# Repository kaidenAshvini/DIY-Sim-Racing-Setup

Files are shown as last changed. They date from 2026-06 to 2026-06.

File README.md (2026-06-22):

# DIY Sim Racing Setup
It's no secret that simulation racing setups are ridiculously expensive (with high end setups reaching thousands of dollars!). I sought to create a DIY Sim Racing Setup, using many materials I and other hobbyists would already have access to, equipped with a force-feedback wheel and 3-pedal setup. In addition, I aimed for the wheel base to be very compact while offering a driving experience comparable to mid-range setups, for a far cheaper cost.

## Specs
The [Wheelbase](CAD/Wheel%20Assembly.step) features a 220W 48V Brushless DC Motor for punchy, high-torque force feedback. It reads position through a 600 P/R Incremental Rotary Encoder, which is responsive and accurate. It is also marginally adjustable, with 3 height settings and 10 degrees of adjustability.

The [Pedals](CAD/Wheel%20Assembly.step) feature torsion springs, adjustable end-stops, and rotary encoders.

## Zine

_Side note:_ I will update this Zine with an IRL picture as soon as I build it

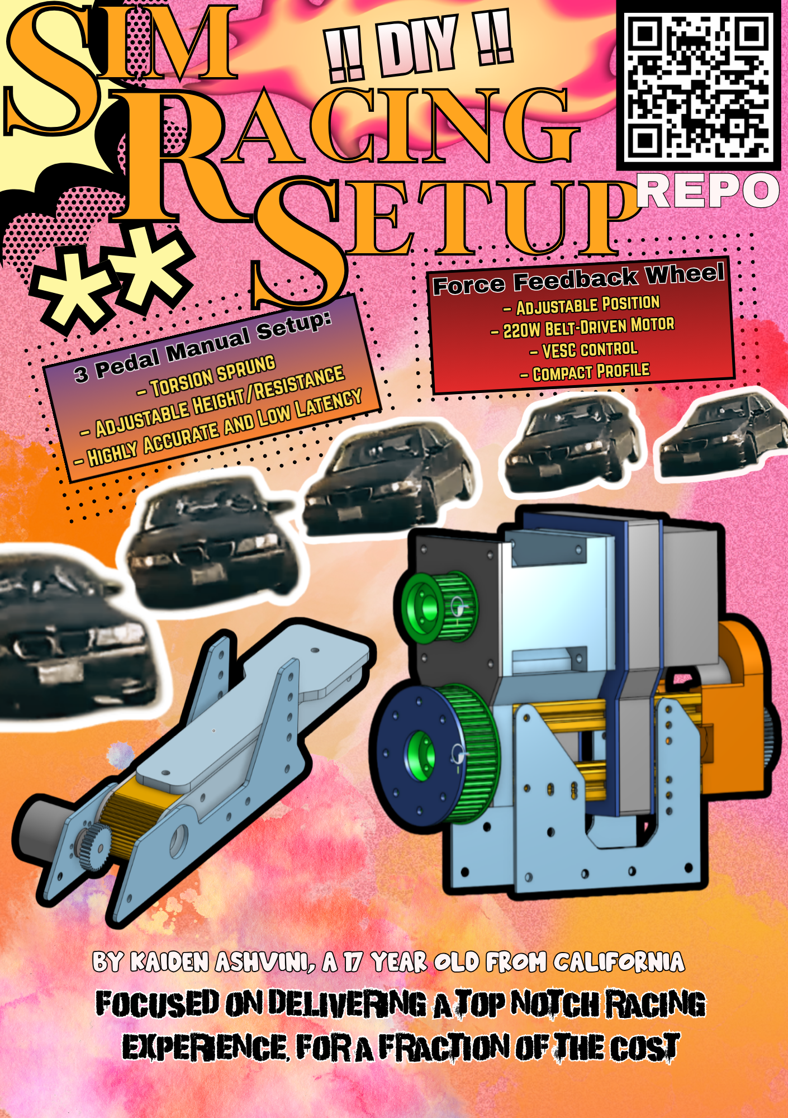
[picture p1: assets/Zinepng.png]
The car is from real pictures of my project car!


## Demo
https://www.youtube.com/watch?v=LTqkKbJHrKM

## Design Philosophy:
While I do have many years of experience on an FTC robotics team (Roboavatars #7303), I am fully a software member. This project was my first attempt at CADing and building a physical project from scratch! Keep this in mind as you read through these designs, and please let me know at kaidenashvini@gmail.com of any mistakes I may have made!

Remember, while I have flushed out a completed project that works for me, feel free to adapt to whatever materials you have on hand. This will keep costs very low, as it did in my case, and will make your personal project far more convenient to complete!

1. ### [Wheelbase](CAD/Wheel%20Assembly.step)
    - **Using 20x20 Extrusions**
        - I have access to plenty of these 20x20 McMaster-Carr extrusions through my robotics team. They are cheap, rigid, and very convenient.
    - **Front Mount**
        - My CAD features a strange design for mounting the force-feedback motor, as it recesses the motor by a few inches. This provides clearance for the inclusion of a shaft coupler (neccesary to extend the motor shaft to mount a 25mm pulley), and it also provides a sturdier rear mounting position.
    - **Motor Rear Mount**
        - The Motor Rear Mount serves to reinforce the motor mount, as features two 3/8ths inch aluminum plates.
    - **Encoder Rear Mount**
        - I geared the encoder to directly to the drive shaft, and found a convenient place to mount it. The mount also keeps the extrusions in place.
        - Gearing an encoder, in my opinion, is preferential to belting it. Gearing will have less lag/backlash, and are also easier to 3d print
    - **3D Printed Pulleys**
        - Metal pulleys are better in *nearly* every way, **but there are a few reasons I chose to 3D print them**. I chose 3D printed pulleys to keep costs down, and because it makes mounting the wheel way easier. I made mine out of annealed carbon nylon (which many have reported online to be very sturdy!), and the design features embedded nuts and space to attach a flange coupler for compactness.
    - **Flipsky Vesc Control**
        - This motor controller is common, and it is listed as compatible with the firmware I've decided to go with for this project. They are relatively common, and I had one on hand. In reality, any controller works as long as it's compatible with the firmware listed in [Software](firmware/README.md).

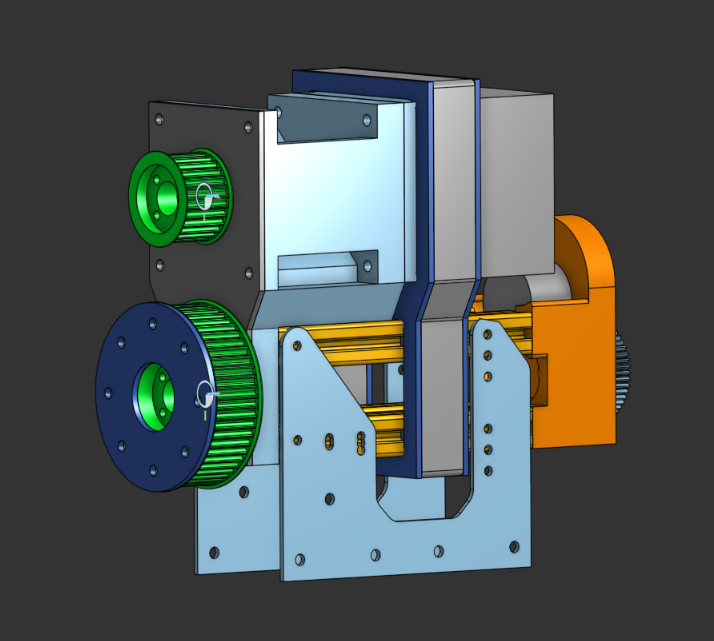
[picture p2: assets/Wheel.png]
Wheel Base, 0 deg Tilt


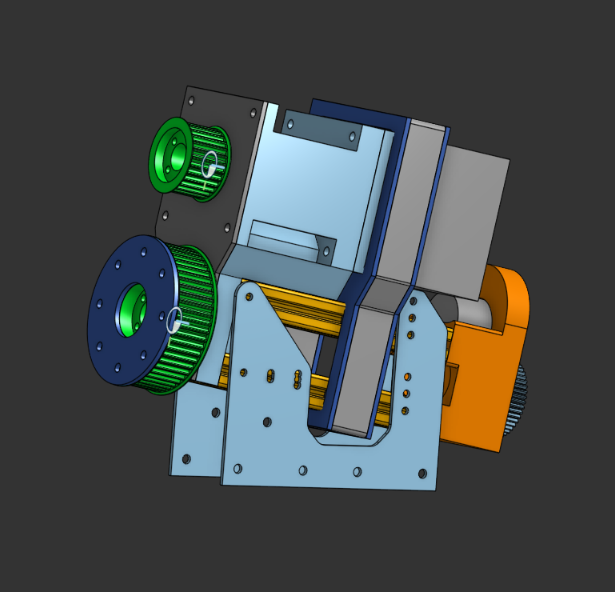
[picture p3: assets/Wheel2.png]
Wheel Base, 10 deg Tilt


2. ### [Pedals](CAD/Pedal%20Assembly.step)
    - **Using Torsion Spring**s
        - I have torsion springs beneath the pedal shafts, which aim offer a realistic feel similar to real pedals.
    - **Pedal Design/Sizing**
        - I based the pedal sizes off of real pedals from IRL car pedals. This (hopefully) makes it easy to heel-toe.
    - **Reading Pedal Position**
        - I chose to use a geared 3D print for low-latency and high-accuracy (by using gear ratios to my advantage)

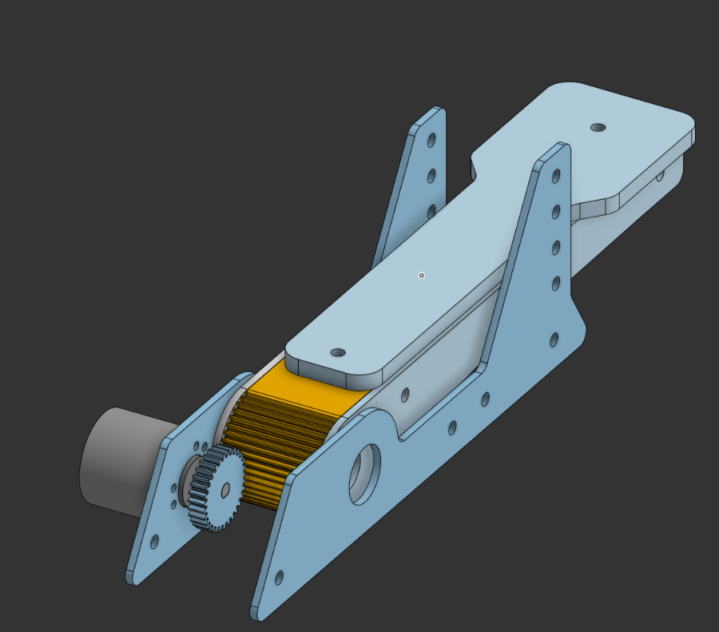
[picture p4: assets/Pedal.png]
Pedals, Front/Top Down View

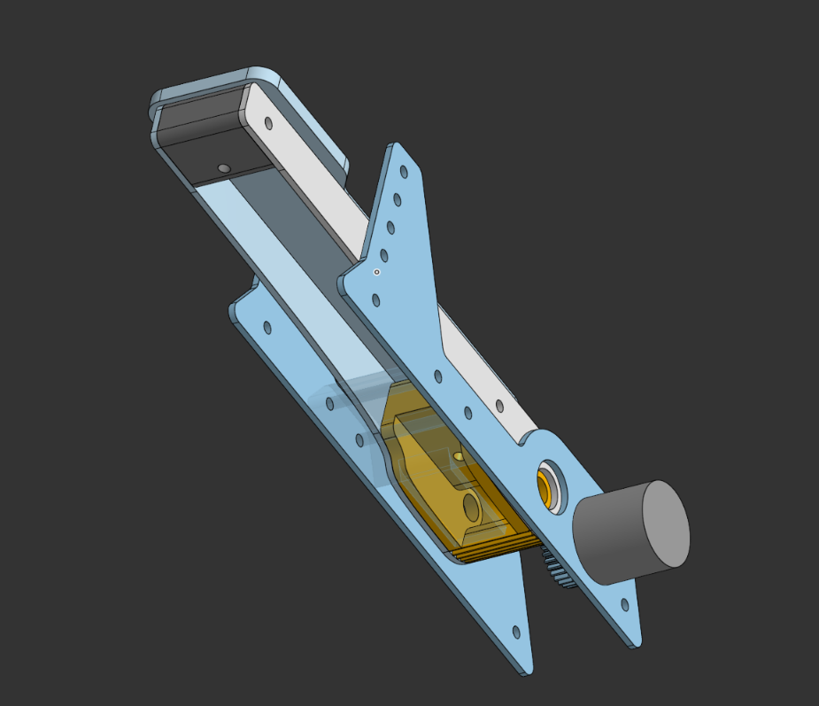
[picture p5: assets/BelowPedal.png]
Pedals, Bottom Torsion Spring Mount View


## Adaptation:
This is a fully-flushed out project that I've put together. I used the resources that I have available to create the best product I could within a reasonable cost. However, I understand that not everyone will have access to the exact same tools and materials as I did. In this case, **IMPROVISE**.

When this project is shipped, an [Adaptation Guide](CAD/README.md) will be added.

## Building Tips:
1. ### Wheel Base
    1. Tapping your Extrusions
        - Use a M5 tap, and preferably a drill press, to tap the ends of your extrusions. For the 1/2 ft extrusions, do it for both sides. Otherwise, tap as neccesary
        - Use a cutting fluid or lubricant, I used WD-40
        - **Take your time**, make sure these come out straight
    2. Printing
        - You will want to print each of these parts to the most sturdy setting you can, with the strongest material you have available, especially if you aren't using the reinforcement plates.
    3. Assembly
        - Mount the Rotary Encoder to the [Encoder Rear Mount](CAD/Wheel/Steering%20Column%20Rear%20Mount.step) (this may be a bit tricky, just keep trying)
        - Mount the [Encoder Rear Mount](CAD/Wheel/Steering%20Column%20Rear%20Mount.step) to 4 tapped extrusions
        - Slide the [Rear Motor Mount](CAD/Wheel/Rear%20Motor%20Mount.step) into the 4 tapped extrusions. Slide the BLDC motor in, as well
        - Mount the [Front Motor Mount](CAD/Wheel/Steering%20Column%20Front%20Mount.step) to the other side of the 4 tapped extrusions. Screw in the 4 motor mounting screws.
        - Attach Flange Bearings (Flange facing outward) to the [Front Motor Mount](CAD/Wheel/Steering%20Column%20Front%20Mount.step) and [Endstop](CAD/Wheel/Steering%20Column%20Rear%20Mount.step)
        - Slide the 12mm dia. x 400mm length D-shaft into the bearings. Mark enough clearance for the Hub Adapter and Shaft Gear (including the flange coupling)
        - Cut the shaft to size. Drop the 14mm x 12mm Shaft Coupler into the top of the Front Motor Mount, and take the smaller peice of the D-shaft to attach to the end of the Shaft Coupler
        - Assemble the gears and pulleys ([Hub Adapter](CAD/Wheel/Hub%20Adapter.step), [Motor Pulley](CAD/Wheel/Motor%20Pulley.step), [Shaft Gear](CAD/Wheel/Shaft%20Gear.step), [Encoder Gear](CAD/Pedal/Encoder%20Gears.step)) using M4 nuts/bolts and the Flange Coupler
        - Test fit and mark the position of the Flange Couplings on the shafts. Disassemble the Pulleys/Gears
        - Attach the Flange Couplings with the shaft mounted and tighten
        - Attach the Gears/Pulleys to their respective Flange Couplings
        - Attach the Belt. This may be easier if you detach the motor output shaft and steering column shaft and slide both in at the same time with the pulley in place
        - Attach the [Encoder Gear](CAD/Pedal/Encoder%20Gears.step) to the encoder
    4. Wiring
        - Use a spare power cord. Strip and attach ferrules to the end. Apply to Power Supply Unit
        - Motor wires to VESC (color corresponding wires)
        - PSU wires to VESC (color corresponding RED/BLACK 10-12 gauge wires)
        - COMM TX/RX/GND wires to STM32 (check wiring diagram for the color correspondance). Ensure that TX/RX are crossed!!
        - Attach 4.7k ohm pull-up resistors to a small jumper wire to both the A and B (Green/White) wires. I used Dupont wires for easy connection.
        - Attach GND,A,B,5v to encoder. Attach the small jumper wire from the previous step to a 3.3V output
        - Splice a USB cable (data transfer, must have 4 wires) with Dupont wires. Refer to your STM32's pinout for the placement of USBs

2. ### Pedals
    1. Side Walls
        - I CNCed my side walls with either aluminum or polycarbonate. You can even print them, although I cannot guarantee their longevity.
    2. Assembly
        - Shave any excess burr or debris off the 3D prints and CNC cuts
        - Mount the Rotary Encoder to a [Pedal Wall](CAD/Pedal/Pedal%20Base.step)
        - Mount 2 Hex Standoffs to a pair of [Pedal Walls](CAD/Pedal/Pedal%20Base.step), one at the hole next to the Rotary Encoder and one on the desired end position
        - Mount the rest of the parts in the [Pedal](CAD/Pedal/Pedal%20(1).step)
    3. Wiring
        - Wire the encoder to 5V, GND, 2 GPIO pins on the ESP32 (internal pull-ups)

**A visual build guide is soon to come, as soon as I document the building process (after approval)**

## Software
Many high-quality DIY sim setups utilize and [OpenFFBoard](https://github.com/Ultrawipf/OpenFFBoard), which comes with all of the force-feedback control that communicates with popular sim games. However, OpenFFBoards are priced at $160, and are produced in Germany. They are fantastic products with great quality, and their software is unmatched in the DIY niche. However, for one reason or another, not everyone can get easy access to one of these boards. Instead, I rely on an ABI encoder-compatible FlipSky VESC controller, which I connect to a cheap power-supply. I also rely on an inexpensive STM32 board.

I implemented custom Force-Feedback and USB HID firmware by adapting the [VNWheel](https://github.com/hoantv/VNWheel) opensource project. This proved to be an immensely difficult task, because the TinyUsb 

This has many implications for developing software, though. The pedals will require seperate microcontrollers. I went with some old ESP32s I had lying around, and also borrowed a RP2040. I wanted to create firmware for multiple MCUs, so that you can use whatever one you want. Either way, both firmwares should be easy to adapt.

### ESP32 (w/out USB HID)
Older ESP32s do not have the correct hardware to support native USB HID, so I designed a way to read serial inputs. If you are using an RP2040 or more expensive/newer ESP32s, the USB HID interfacing should be extremely straightforward.

I will also add support for the newer ESP32s and RP2040s as soon as I get my hands on them.

### Electronics

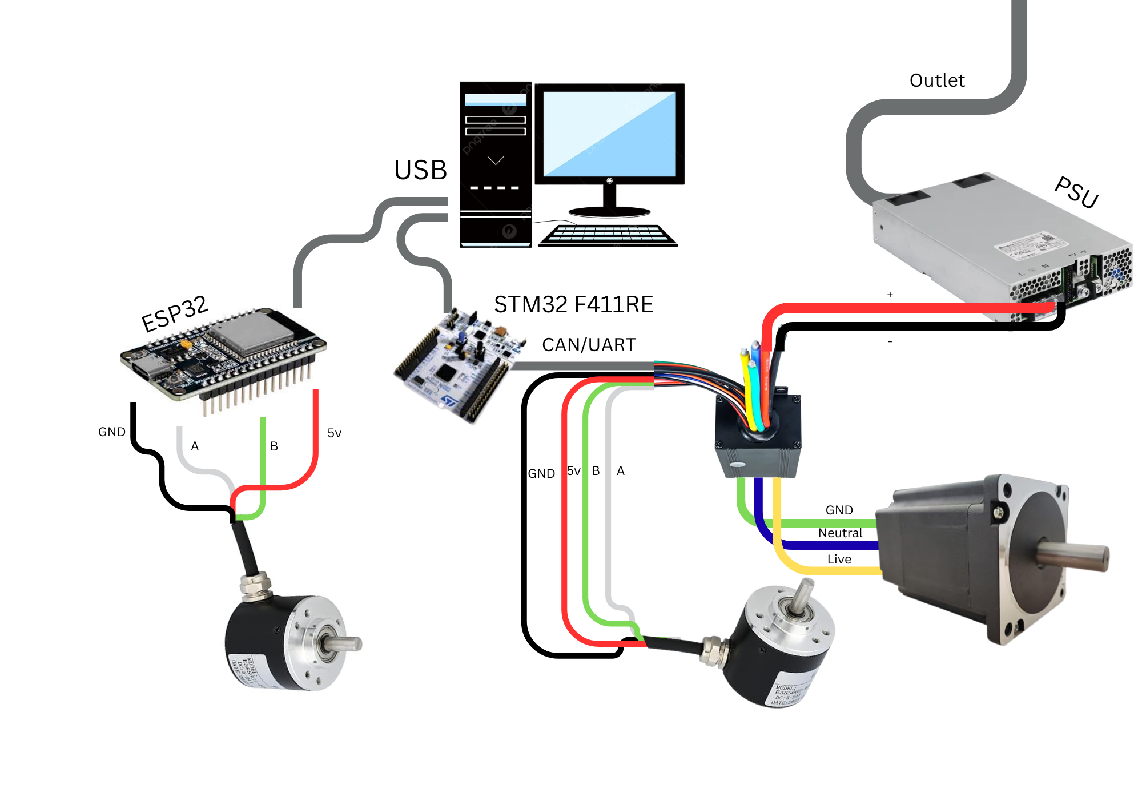
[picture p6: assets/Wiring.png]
Simplified Wiring Diagram


### BOM
About half of the cost in materials was self-sourced from previous projects, robotics teams, friends, etc. Shoutout to Theodore for challenging me to make a build for the same cost.

Learn more in [Adaptation Guide](CAD/README.md).

The BOM can be found [here](BOM/BOM.csv).

### IRL Pictures!!

I know its messy...

With/Without Wheel:
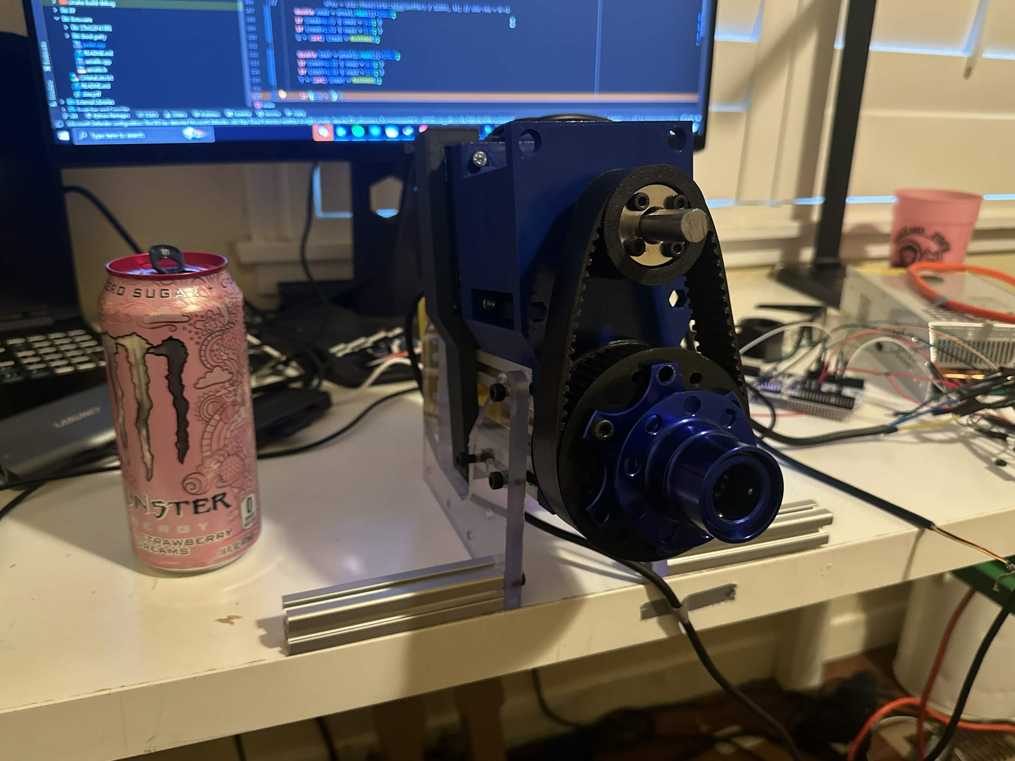
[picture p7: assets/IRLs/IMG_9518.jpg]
Without

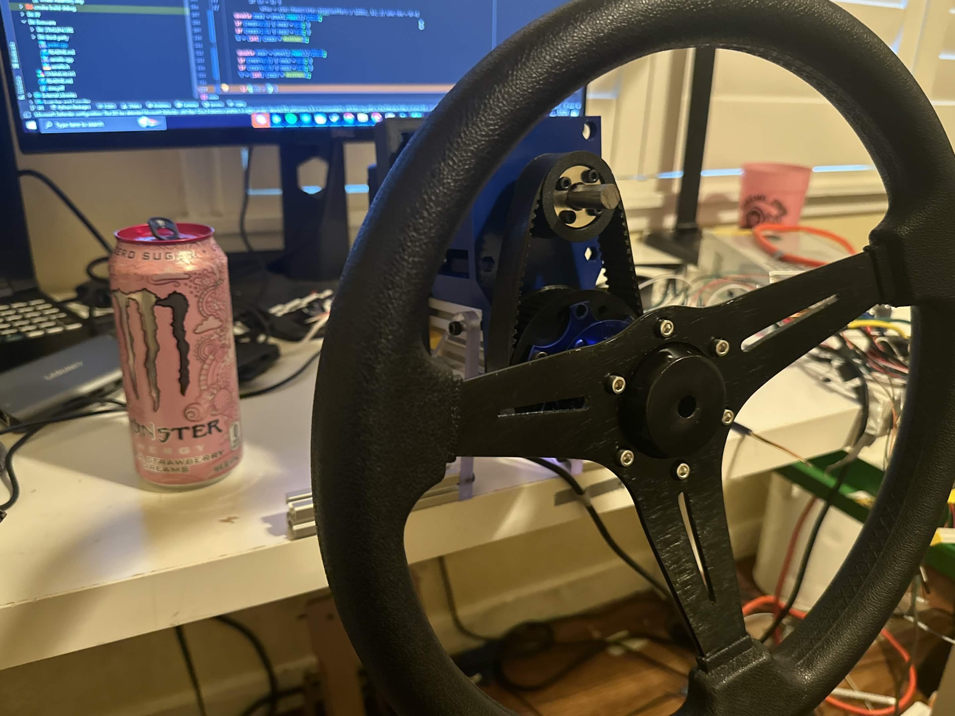
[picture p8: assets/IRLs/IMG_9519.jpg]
With


Pedal:
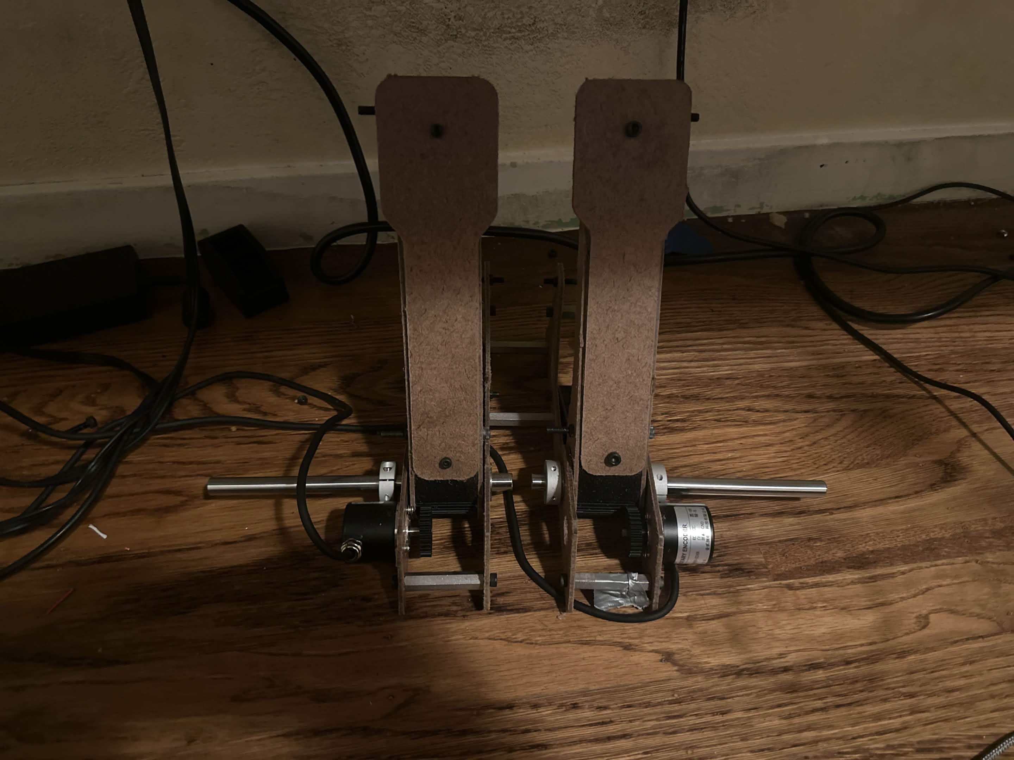
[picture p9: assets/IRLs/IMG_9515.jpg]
Pedal


Wiring:
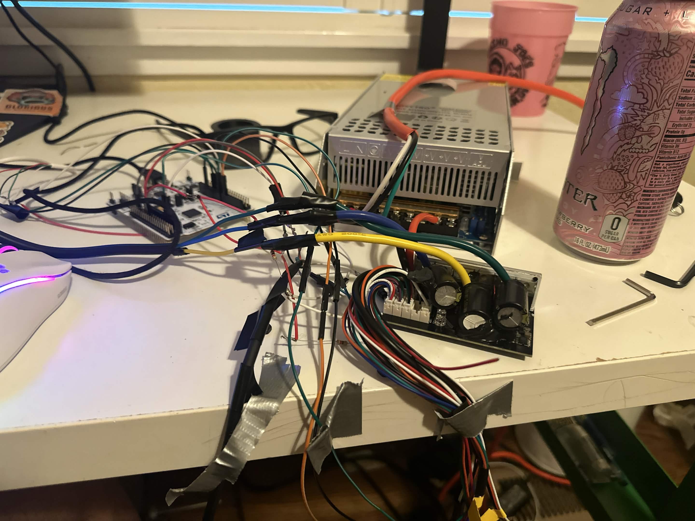
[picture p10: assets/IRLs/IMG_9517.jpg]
Wiring


Wheelbase Internals:
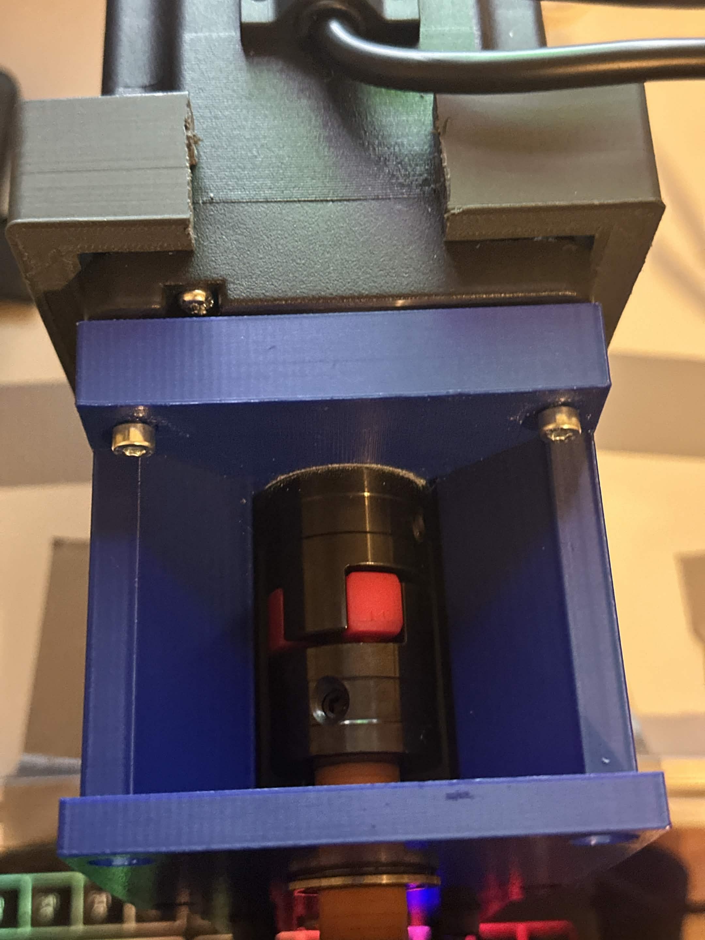
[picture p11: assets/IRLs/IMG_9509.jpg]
Shaft Coupler

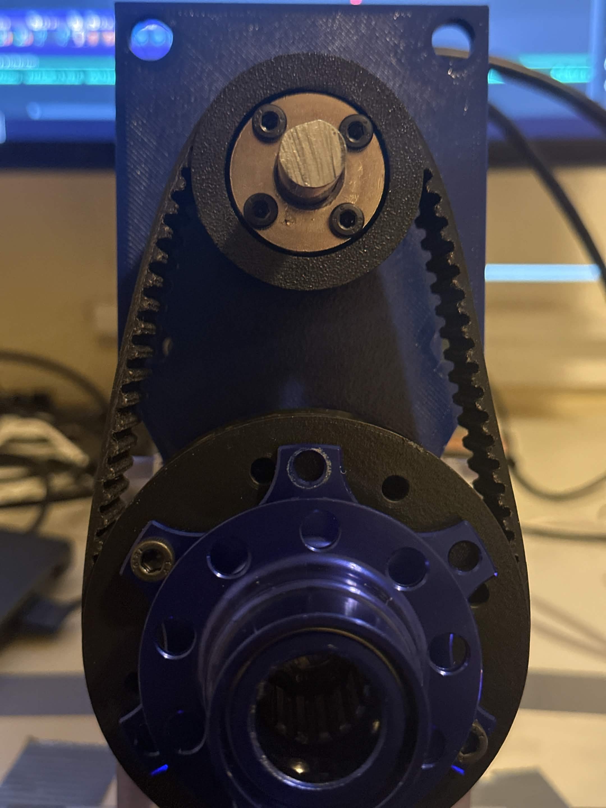
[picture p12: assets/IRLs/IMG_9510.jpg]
Pulley


### Contact

Discord: sheikaheye123

Gmail: kaidenashvini@gmail.com

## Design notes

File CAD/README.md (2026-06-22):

# Tips for Adaptation:

## Motor
Use any motor you would like (Brushless DC Motors are preferred). Adjust the mount size accordingly.

## CNC Parts
These parts can either be printed OR CNCed. Any thickness is fine.

## Pedals
Pedals can be any width. Adjust the plastic connectors accordingly or use spacers.

## Motor Controllers
You may swap the VESC for a suitable motor controller. Use the [EMC Pro](https://github.com/ebolzMagy/EMCFFBV2) software instead if you plan on doing so (it will be far easier to setup but does cost $10 dollars)

## STM32
Any board that supports USB and UART or CAN will work. If the board supports CAN (F407), use [OpenFFBoard](https://github.com/Ultrawipf/OpenFFBoard).

## Shafts
Use any shaft you'd like (preferably over 8mm). Adjust the holes in the Wheelbase and Pedals accordingly.

### Good Luck and Happy Building!!

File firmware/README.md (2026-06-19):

# Software
## Third Party Libraries

| Library | Usage | Link |
|---| - | - |
| Serialib | Allows C++ to read serial input from ESP32 | https://github.com/imabot2/serialib | 
| vJoy SDK | Allows C++ USB HID interfacing for joystick inputs | https://sourceforge.net/projects/vjoystick/files/Beta%202.x/SDK/ |
| hidapi-win | Allows low-level USB HID interfacing | https://github.com/libusb/hidapi |
| VNWheel | Open-source Force Feedback for Arduinos | https://github.com/hoantv/VNWheel |
| TinyUSB | HID interfacing with the STM32 | https://github.com/hathach/tinyusb |
| VescUart | Sending current commands over UART | https://github.com/SolidGeek/VescUart |

## Building

You will need to put the vJoyInterface.dll (specifically from third-party/vjoy/lib/amd64/) in the cmake-build-debug folder (for CLion, should be wherever your .exe file is).

I will remove this soon, because I need to flush out the firmware with the physical parts before completing it.

The STM32F411RE folder should open with Arduino IDE for flashing.

## Future Work (Coming Soon)

After completing the build, I will add support for newer ESP32s and RP2040s for pedal controls, as well. I need to source these myself to solidly test them, so I cannot configure them just yet.

I have written some low-level USB HID Descriptors for this task, included in the image below:

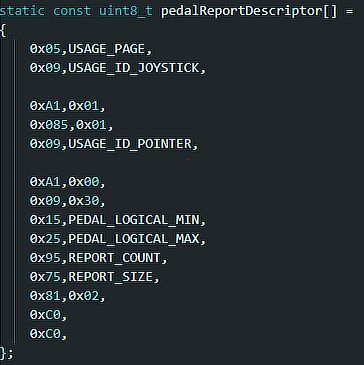
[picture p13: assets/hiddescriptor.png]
A sneak peek of what's to come!!


**Expect a full firmware/build guide once the build is started/completed!**

## Sources (Arduino IDE Sketches for ESP32 Firmware):

I used this tutorial to read ABI encoder outputs: https://www.youtube.com/watch?v=Y6BjnfwfzKE

## DIY Force-Feedback software
While originally not my intention, I ended up adapting the VNWheel library to implement custom force-feedback firmware to the STM32. This will be explained more in depth in the demo video (once it is shipped)

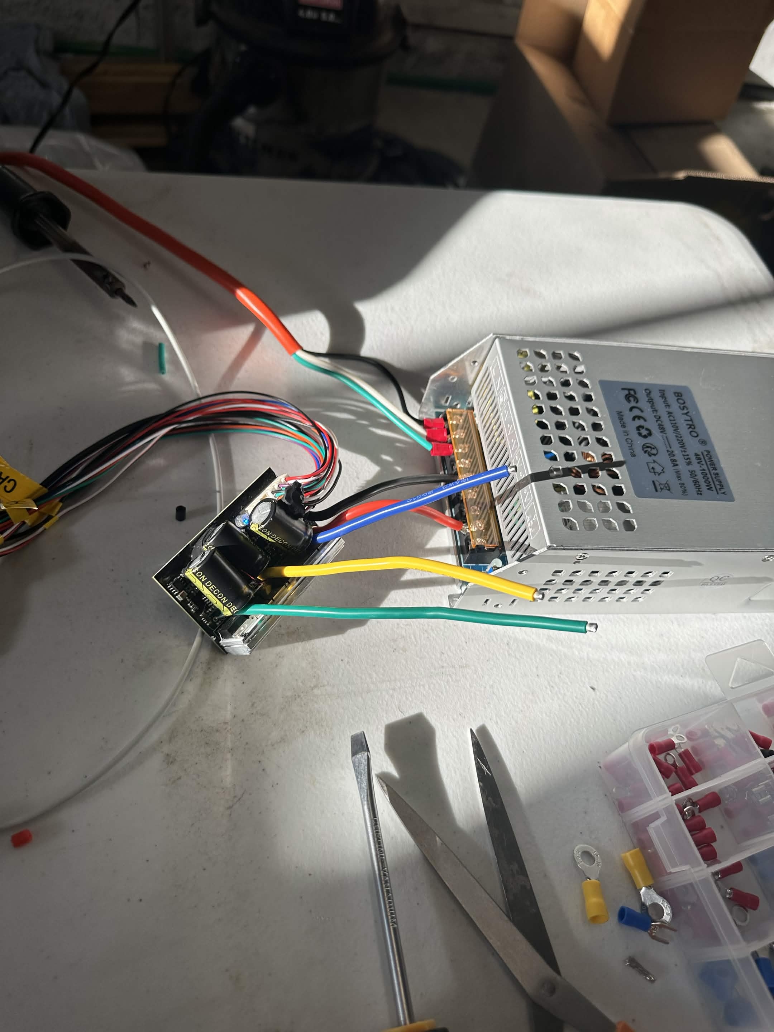
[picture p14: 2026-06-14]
assets/VESC.jpg

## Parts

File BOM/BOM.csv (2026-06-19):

PURCHASED ITEMS
Name | Description | Link | Units | Unit Price | Qty | Line Price | Running Total
Hub Adapter | 6-Hole Universal Pattern (70mm) | https://a.co/d/0caWlYnZ | Each | $27.99 | 1 | $27.99 | $27.99
Hall Effect Sensor | KY003, 3144E A3144, DC 3.3V-5V | https://a.co/d/04nWw3zB | Each | $0.86 | 10 | $8.60 | $36.59
Brushless DC Motor | 220W, 3000rpm, 48V | https://a.co/d/08rhArJE | Each | $80.50 | 1 | $80.50 | $117.09
Flange Couplings | 12mm ID x 30m OD | https://a.co/d/0i7bd3jh | Each | $1.90 | 4 | $7.60 | $124.69
Shaft Coupler | 14mm to 12mm (IDs) x 30mm OD | https://a.co/d/09o9XnUK | Each | $20 | 1 | $20 | $144.69
Amazon (Prime) Shipping | $0 |  |  |  |  | $0 | $144.69
Amazon (Prime) Local/State Tax | $14.12 |  |  |  |  | $14.12 | $158.81
D-Shaft | 12mm Diameter, 400mm Length, 6mm Flat Width | https://www.mcmaster.com/products/shafts/rotary-shafts-2~/length~100-mm/length~400-mm/rotary-shafts-2~shaft-type~d-profile/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 | Each | $18.71 | 1 | $18.71 | $177.52
Torsion Spring | 225 Deg, 0.48in Shaft Diameter | https://www.mcmaster.com/products/torsion-springs/shaft-diameter~0-48/deflection-angle~225/ | Each | $2.38 | 6 | $14.28 | $191.80
Pulley Belt | HTD5, 25mm Width, 80 Teeth, 400mm Trade Size | https://www.mcmaster.com/products/timing-belts/high-torque-htd-timing-belts-2~~/width~25-mm/number-of-teeth~80/ | Each | $44.36 | 1 | $44.36 | $236.16
McMaster-Carr Shipping |  | $14.50 |  |  |  | $14.50 | $250.66
McMaster-Carr Local/State Tax |  | $0 |  |  |  | $0 | $250.66
SELF-SOURCED ITEMS (Not compensated by Hack Club)
Name | Description | Link | Units | Unit Price | Qty | Line Price | Running Total | Source
Steering Wheel | 13.8" Diameter, 3-spoke, 6-Hole Universal Pattern (70mm) | https://a.co/d/0jdjjv3R | Each | $22.88 | 1 | $22.88 | $273.54 | Personal Supply
Rotary-Shaft | 12mm Diameter, 100mm Length | https://www.mcmaster.com/products/shafts/rotary-shafts-2~/length~100-mm/rotary-shafts-2~shaft-type~round/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 | Each | $11.62 | 2 | $23.24 | $296.78 | Robotics Team
Rotary Encoder | 600 P/R, AB 2-Phase Quadrature Output (open-collector), 5-24V | https://a.co/d/07jE8QEV | Each | $14.99 | 4 | $59.96 | $356.74 | Robotics Team
Flanged Bearing | F6901ZZ, 12mm ID x 24mm OD | https://a.co/d/0j7CwzQN | Each | $1.25 | 10 | $12.50 | $369.24 | Robotics Team
Shaft Collar | 12mm ID x 30mm OD | https://a.co/d/0fmp9A3E | Each | $2.42 | 1 | $2.42 | $371.66 | Robotics Team
Extrusion (T-Slotted Framing Rails) | 20mm x 20mm, 6" length | https://www.mcmaster.com/products/extrusions/t-slotted-framing-and-fittings~/t-slotted-framing-rails-4/rail-height~20-mm/finish~anodized/length~6/length~1-2-f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 | Each | $3.75 | 7 | $26.25 | $397.91 | Robotics Team
Standoff | M5, 10mm Hex Size, 52mm | https://www.mcmaster.com/products/standoffs/standoffs-2~/female-threaded-hex-standoffs~~/thread-size~m5/length~52-mm/performance~lightweight/ | Each | $3.91 | 4 | $15.64 | $413.55 | Robotics Team
Power Supply Unit | 48V, 20.8A, 1000W | https://a.co/d/0fD26eDp | Each | $50.99 | 1 | $50.99 | $464.54 | Personal Supply (Very overkill for this project)
STM32 | Nucleo-64, F411RE | https://a.co/d/01KzO2nj | Each | $25.42 | 1 | $25.42 | $489.96 | Personal Supply
ESP32 | NodeMCU (ESP-32S) | https://a.co/d/0g8DS4Zf | Each | $5.60 | 1 | $5.60 | $495.56 | Personal Supply
Flipsky VESC | 75100, 75V, 100A | https://a.co/d/06qzeMMU | Each | $75.99 | 1 | $75.99 | $571.55 | Personal Supply (Also overkill)
SELF-SOURCED MISC. RESOURCES (Not compensated by Hack Club)
Name | Description | Link | Units | Unit Price | Qty | Line Price | Running Total
M5 Assorted Bolts/Nuts | M5x8/10/12/16/20/25/30/35 | https://a.co/d/0ctkiRn3 | Each (kit) | $9.99 | 1 | $9.99 | $581.54
M4 Assorted Bolts/Nuts | M4x6/8/12/16/20/30 | https://a.co/d/0cXDtAtJ | Each (kit) | $9.99 | 1 | $9.99 | $591.53
Filament | PAHT-CF, PLA | https://a.co/d/0477rVy3 | Kg | $39.99 | 0.3 | $12.00 | $603.53
SELF-SOURCED TOOLS (Not compensated by Hack Club)
Drill Press
M5 0.8 Spiral Flute Tap
CNC
3D Printer
Filament Dryer

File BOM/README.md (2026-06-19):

# Sourcing

## Why Amazon?
I am well aware that Hack Club prefers sourcing electronics from less mainstream distributors than Amazon. However, for my case, I ended up saving about 20 dollars and weeks worth of waiting through using Amazon with my parent's Prime membership (free shipping and heavily reduced fees). Because I bought so few electronics, and the ones I did buy were heavy/large, shipping from Aliexpress would have costed upwards of 40 dollars, not including myriad other taxes and fees. Even if I did save some money from buying a cheaper part, the shipping would have quickly covered that cost.
## Why McMaster-Carr?
McMaster-Carr is a local company that I frequently rely on for robotics parts. They have some of the best prices for highly specified materials, and because they are very local, shipping is fast and very cheap. They offer a fixed shipping fee for as many items as you want, making bulk/bundled purchases ideal.

## Self Sourcing
I was luckily able to self-source many parts for free from friends, robotics team, and previous project.

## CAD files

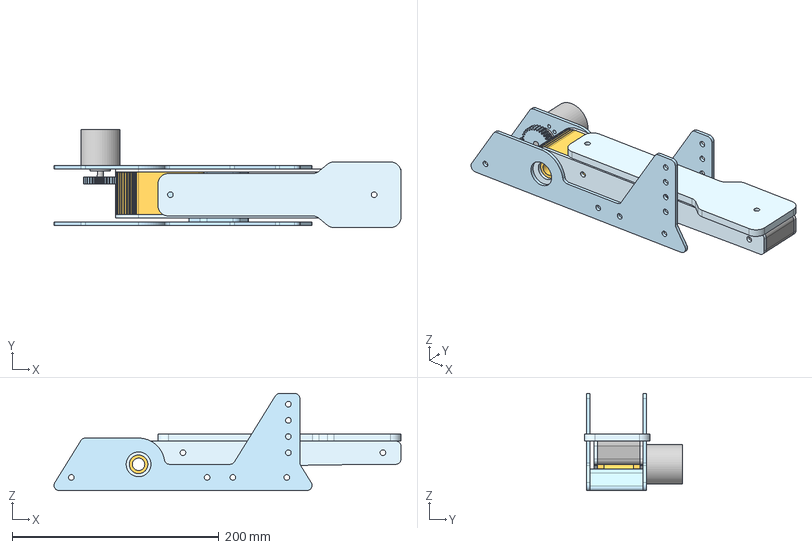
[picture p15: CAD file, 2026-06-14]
CAD/Pedal Assembly.step
335.9 x 94.9 x 94.0 mm
e38s6g5 600b g24n
Spur 1M 43T
Spur 1M 31T

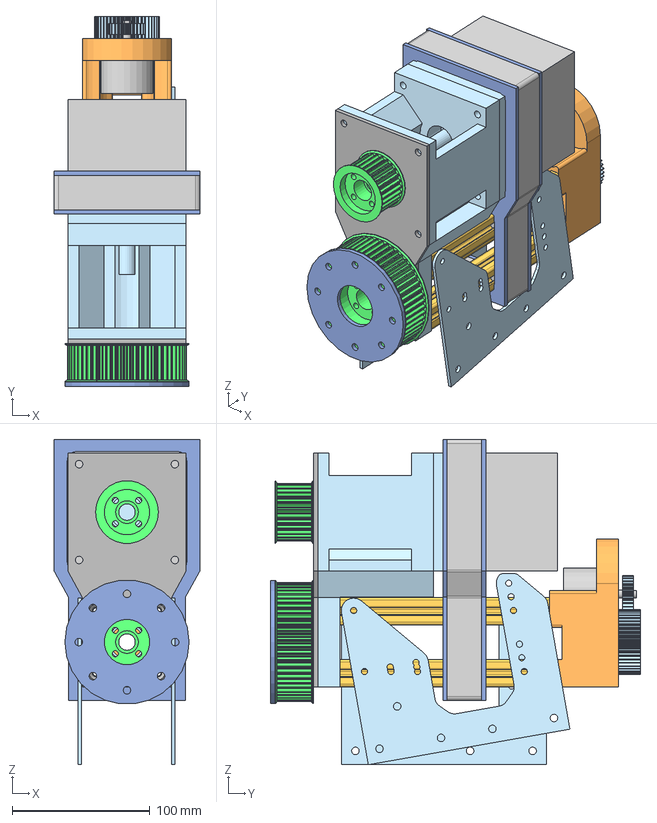
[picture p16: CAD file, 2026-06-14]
CAD/Wheel Assembly.step
105.8 x 268.8 x 236.4 mm
[LS] Pulley HTD5 27T
5537T011_T-Slotted Framing x 4
Spur 1M 25T
[LS] Pulley HTD5 55T
Spur 1M 45T
e38s6g5 600b g24n

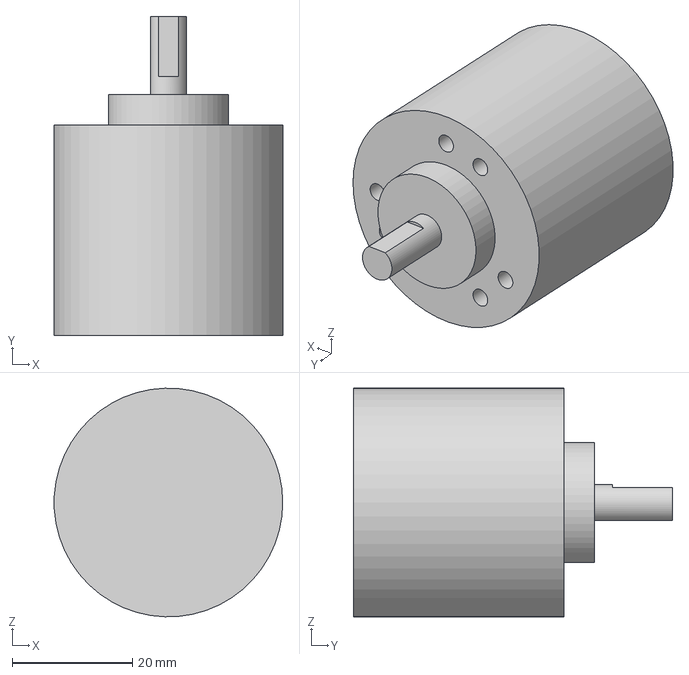
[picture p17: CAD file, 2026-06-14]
CAD/CAD Imports/e38s6g5 600b g24n.step
38.0 x 53.0 x 38.0 mm

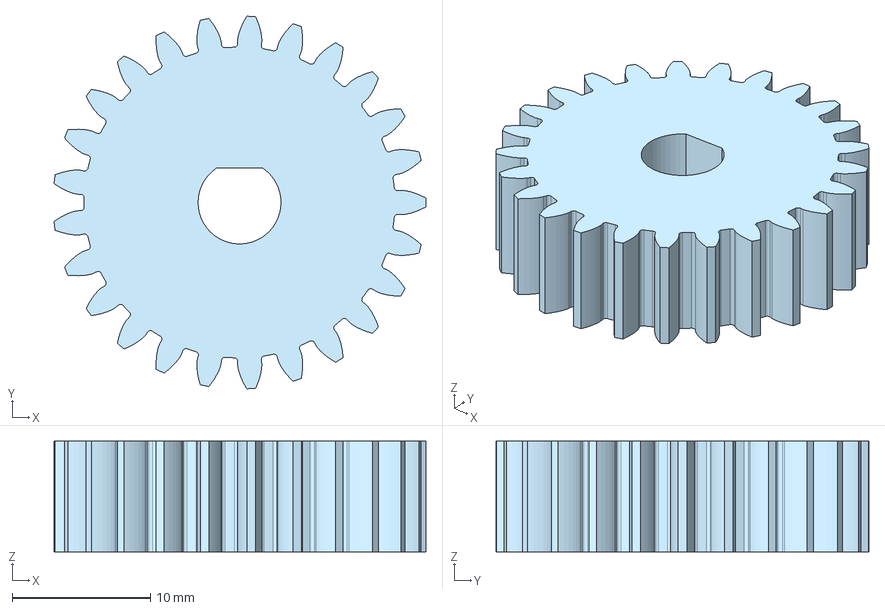
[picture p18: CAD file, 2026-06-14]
CAD/Pedal/Encoder Gears.step
26.9 x 27.0 x 8.00 mm

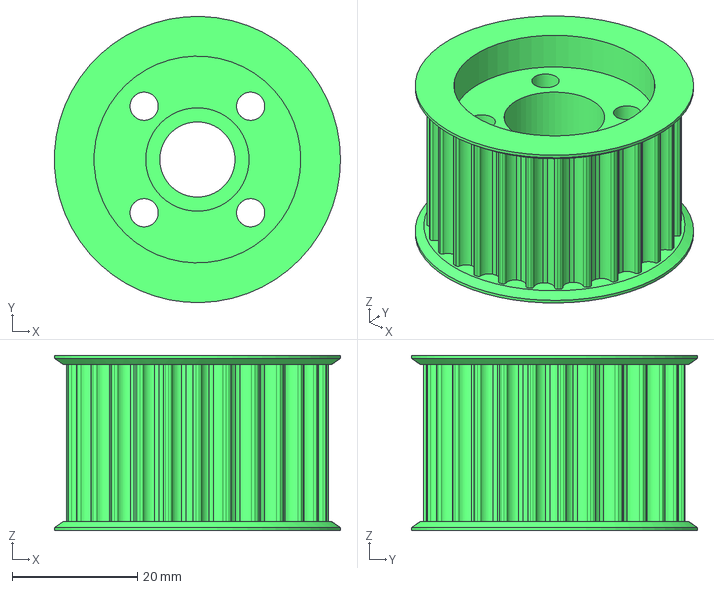
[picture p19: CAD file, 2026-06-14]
CAD/Wheel/Motor Pulley.step
45.6 x 45.7 x 28.0 mm

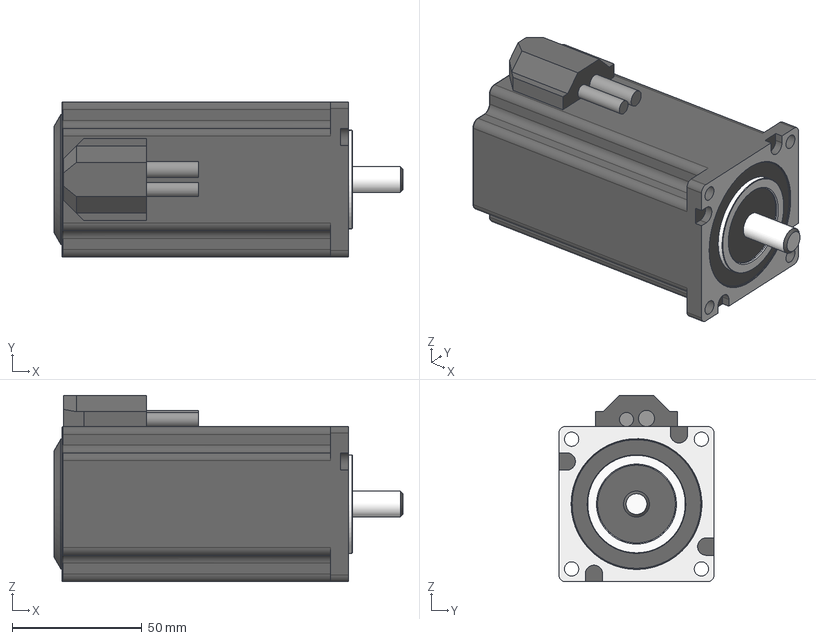
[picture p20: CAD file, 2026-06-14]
CAD/CAD Imports/Nema24_ClosedLoop.step
134.5 x 59.8 x 71.8 mm

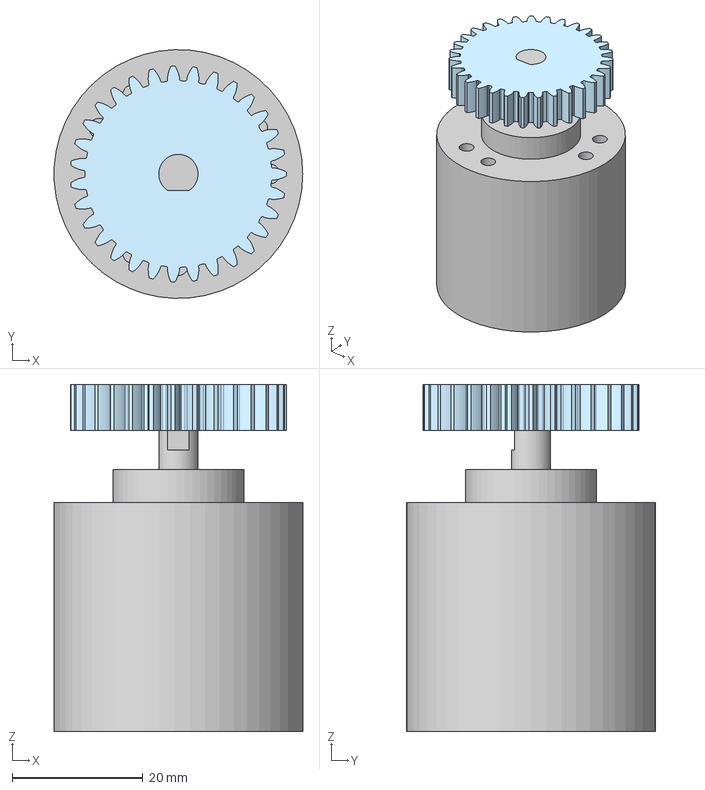
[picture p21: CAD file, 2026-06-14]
CAD/Pedal/Pedal Encoder Gear.step
38.0 x 38.0 x 53.0 mm

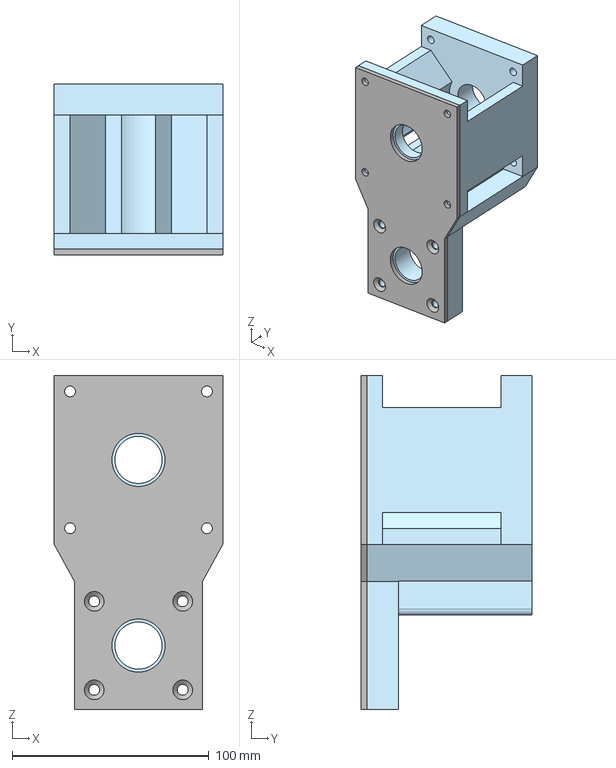
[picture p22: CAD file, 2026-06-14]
CAD/Wheel/Steering Column Front Mount.step
85.8 x 87.2 x 169.8 mm

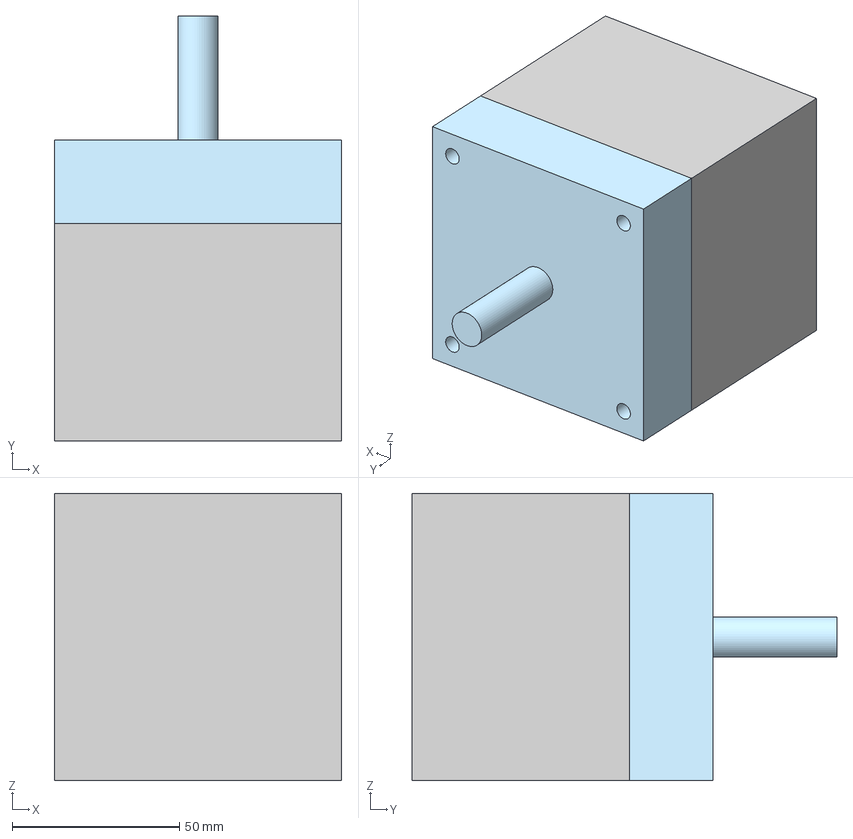
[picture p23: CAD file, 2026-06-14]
CAD/CAD Imports/Part Studio 2.step
85.8 x 127.0 x 85.8 mm

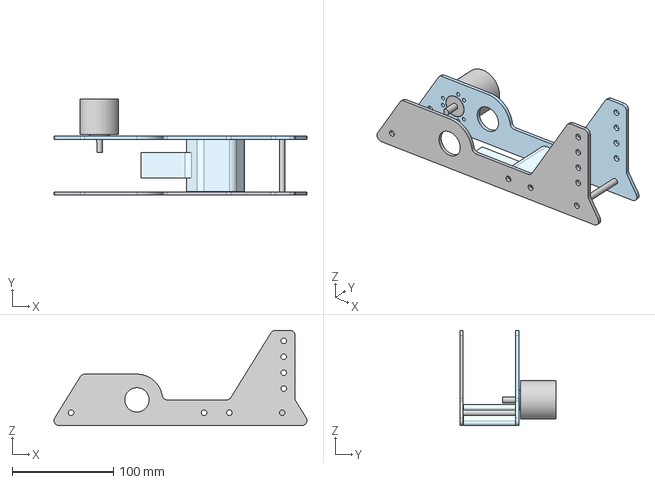
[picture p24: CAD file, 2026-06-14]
CAD/Pedal/Pedal Base.step
249.8 x 95.2 x 94.0 mm

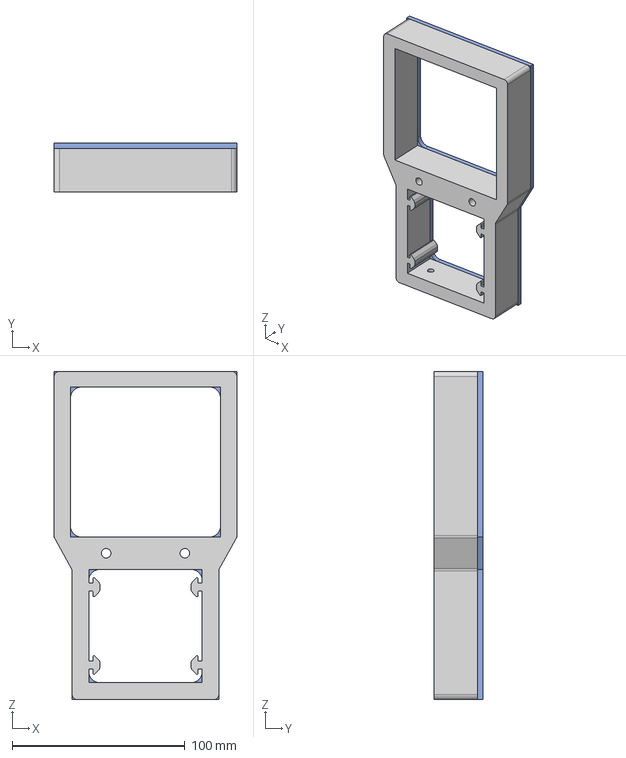
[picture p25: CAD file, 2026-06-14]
CAD/Wheel/Rear Motor Mount.step
105.8 x 28.2 x 189.8 mm

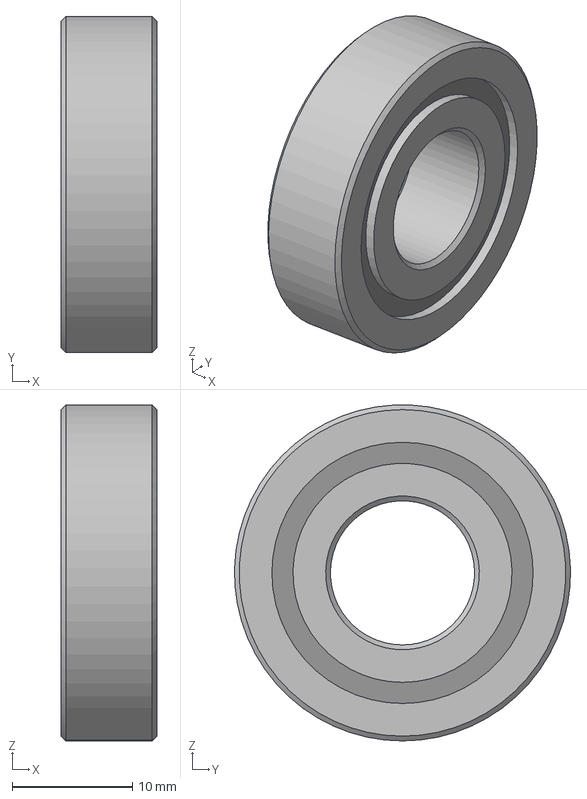
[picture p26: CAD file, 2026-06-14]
CAD/CAD Imports/6001ZZ Bearing.SLDPRT.step
8.00 x 28.0 x 28.0 mm

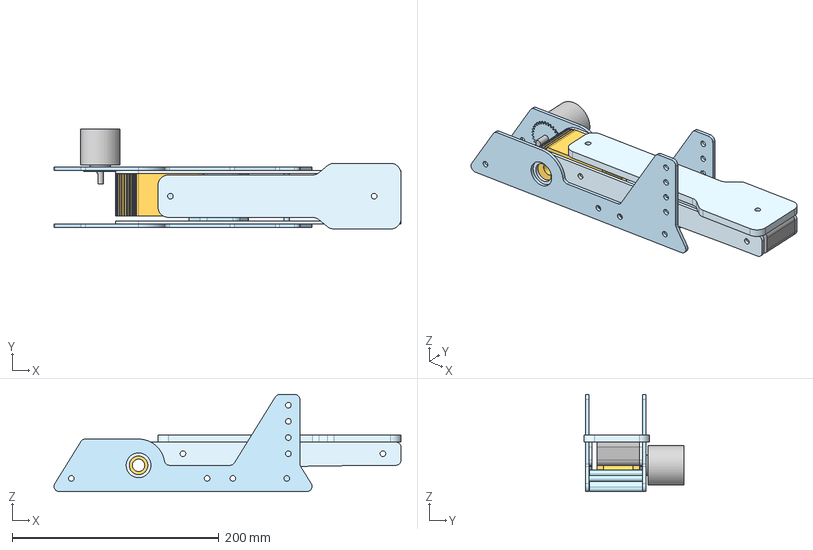
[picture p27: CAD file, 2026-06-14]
CAD/Pedal/Pedal (1).step
335.9 x 96.8 x 94.0 mm

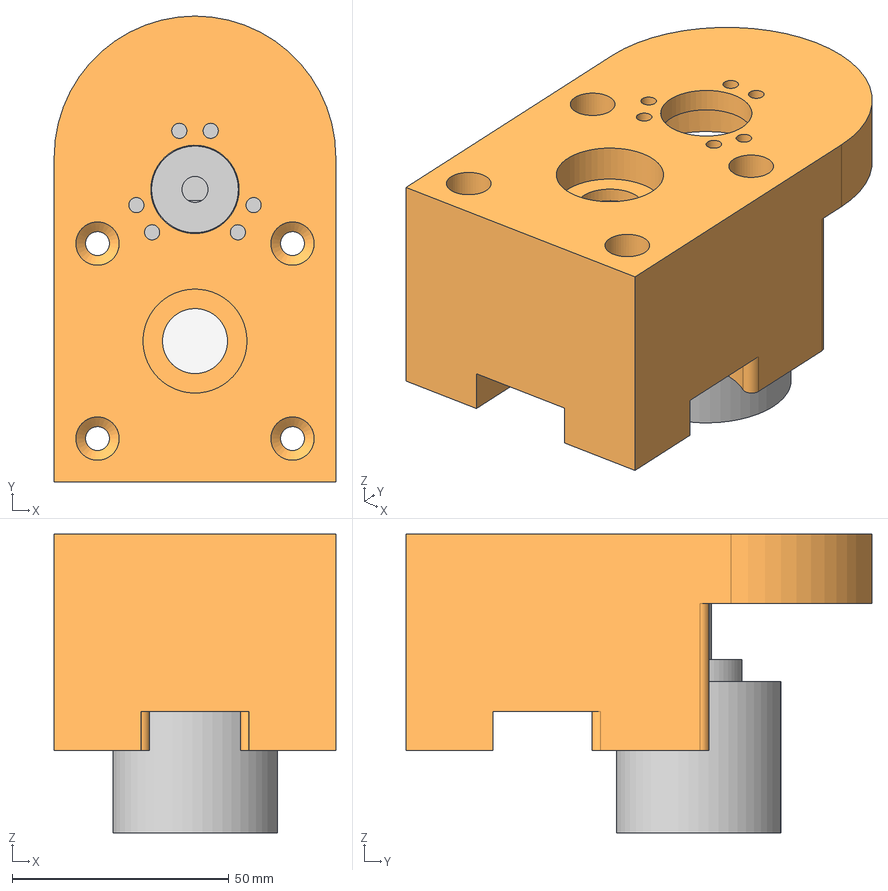
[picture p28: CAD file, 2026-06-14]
CAD/Wheel/Steering Column Rear Mount.step
65.0 x 107.5 x 69.0 mm

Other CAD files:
CAD/Wheel/Table Mount.step
CAD/Wheel/Shaft Gear.step
CAD/Wheel/Hub Adapter.step
CAD/CAD Imports/5537T011_T-Slotted Framing (1).step
CAD/CAD Imports/5537T011_T-Slotted Framing.STEP.x_t
CAD/CAD Imports/Nema24_ClosedLoop.x_t
CAD/CAD Imports/e38s6g5 600b g24n.x_t

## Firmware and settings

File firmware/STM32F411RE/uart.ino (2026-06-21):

#include <VescUart.h>
#include <HardwareTimer.h>
#include <Arduino.h>
#include "Encoder.h"
#include "FfbEngine.h"
#include "FfbReportHandler.h"
#include "WheelConfig.h"
#include "WHID.h"


VescUart vUart;
HardwareSerial vSerial(PA10,PA9);
HardwareSerial DebugSerial(PA3, PA2); 

int32_t totalForce;

Encoder enc;
FfbEngine ffbEngine;
WheelConfig wheelConfig;

WheelReport wr;

#define MAXAMPS 6.0


// void FfbEngine::SetFfb(FfbReportHandler* reporthandler) {
//   ffbReportHandler = reporthandler;
// }

void setup() {
  DebugSerial.begin(9600);
  delay(1000);

  vSerial.begin(115200);
  vUart.setSerialPort(&vSerial);

  HID().setup();

  ffbEngine.SetFfb(&ffbReportHandler);
  ffbEngine.SetGain(wheelConfig);

  memset(&wr, 0, sizeof(wr));
  HID().SendReport(HID_REPORTID_WHEEL, &wr, sizeof(wr));

  // // TEMP TEST: force one constant FFB effect on.
  // volatile TEffectState& test = ffbReportHandler.gEffectStates[1];

  // test.state = MEFFECTSTATE_PLAYING;
  // test.effectType = USB_EFFECT_CONSTANT;
  // test.magnitude = 10000;                 // full positive force
  // test.gain = 255;                        // full effect gain
  // test.duration = USB_DURATION_INFINITE;  // never expires
  // test.elapsedTime = 0;
  // test.startTime = millis();

  ffbReportHandler.devicePaused = false;

  enc.setup();
}
static uint32_t lastDebugMs = 0;
static uint32_t lastHidUs = 0;

static uint32_t lastFfbUs = 0;

#define USEDEBUG false

void loop() {
  TinyUSB_Device_Task();
  enc.loop();



  wr.x = enc.currentPosition;
  wr.y = 0;
  wr.rx = 0;
  wr.ry = 0;
  wr.z =0;
  wr.rz =0;
  wr.buttons = 0;

  totalForce = ffbEngine.ForceCalculator(enc);    
  totalForce = constrain(totalForce, -255, 255);

  if (USEDEBUG && millis() - lastDebugMs >= 1000) {
    DebugSerial.print("Pos=");
    DebugSerial.print(enc.currentPosition);
    DebugSerial.print(" Force=");
    DebugSerial.println(totalForce);

  DebugSerial.println();

for (uint8_t i = 0; i <= MAX_EFFECTS; i++) {
  volatile TEffectState& e = ffbReportHandler.gEffectStates[i];

  if (e.state != 0 || e.effectType != 0) {
    DebugSerial.print(" S");
    DebugSerial.print(i);

    DebugSerial.print(" state=");
    DebugSerial.print(e.state);

    DebugSerial.print(" play=");
    DebugSerial.print((e.state & MEFFECTSTATE_PLAYING) ? 1 : 0);

    DebugSerial.print(" type=");
    DebugSerial.print(e.effectType);

    DebugSerial.print(" mag=");
    DebugSerial.print(e.magnitude);

    DebugSerial.print(" gain=");
    DebugSerial.print(e.gain);

    DebugSerial.print(" cp=");
    DebugSerial.print(e.cpOffset);

    DebugSerial.print(" posK=");
    DebugSerial.print(e.positiveCoefficient);

    DebugSerial.print(" negK=");
    DebugSerial.print(e.negativeCoefficient);

    DebugSerial.print(" dead=");
    DebugSerial.println(e.deadBand);

    DebugSerial.print(" dur=");
    DebugSerial.print(e.duration);

    DebugSerial.print(" elapsed=");
    DebugSerial.print(e.elapsedTime);

    DebugSerial.print(" posSat=");
DebugSerial.print(e.positiveSaturation);

DebugSerial.print(" negSat=");
DebugSerial.print(e.negativeSaturation);


    bool active =
      (e.state & MEFFECTSTATE_PLAYING) &&
      ((e.elapsedTime <= e.duration) ||
      (e.duration == USB_DURATION_INFINITE)) &&
      !ffbReportHandler.devicePaused;

    DebugSerial.print(" active=");
    DebugSerial.println(active ? 1 : 0);

    DebugSerial.println();
  }

  // DebugSerial.println();
  // DebugSerial.print("curvel");
  // DebugSerial.println(enc.currentVelocity);
  // DebugSerial.print("maxvel");
  // DebugSerial.println(enc.maxVelocity);
  //   DebugSerial.print("curAcc");
  // DebugSerial.println(enc.currentAcceleration);
  //   DebugSerial.print("maxAcc");
  // DebugSerial.println(enc.maxAcceleration);

  // DebugSerial.print("Constant Hits");
  // DebugSerial.println(dbgConstantCaseHits);


  }

    lastDebugMs = millis();
  }
  

  if (micros() - lastHidUs >= 2000) {
    HID().SendReport(HID_REPORTID_WHEEL, &wr, sizeof(wr));
    lastHidUs = micros();
  }
  uint32_t nowUs = micros();

  if ((uint32_t)(nowUs - lastFfbUs) >= 1000) {
    lastFfbUs = nowUs;

    totalForce = ffbEngine.ForceCalculator(enc);
    totalForce = constrain(totalForce, -255, 255);
  }

  vUart.setCurrent(constrain(((float) -totalForce/255) * MAXAMPS,-MAXAMPS,MAXAMPS));

}

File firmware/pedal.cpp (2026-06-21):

    #include <iostream>
#include <cmath>
#include "serialib.h"
#include "public.h"
#include "vjoyinterface.h"

#pragma comment( lib, "VJOYINTERFACE" )

#define DEV_ID 1 //general device thing i frogot what it called

#if defined (_WIN32) || defined(_WIN64)
//for serial ports above "COM9", we must use this extended syntax of "\\.\COMx".
//also works for COM0 to COM9.
//https://docs.microsoft.com/en-us/windows/win32/api/fileapi/nf-fileapi-createfilea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
#define SERIAL_PORT_THROTTLE "\\\\.\\COM17"
#define SERIAL_PORT_BRAKE "\\\\.\\COM10"
#endif
//https://github.com/shauleiz/vJoy/blob/master/SDK/c%23/FeederDemoCS/Program.cs
#define useSerial false

#define MAXRANGE 32767



JOYSTICK_POSITION iReport = { 0 };

class serialDev {
public:
    int baud;
    char errorOpening;
    serialib serial;
    char buf[256*2];
    int n;

    double curPos = 0;

    serialDev(int _baud, bool isThrottle) {
        this->baud = _baud;
        if (isThrottle) {
            errorOpening = this->serial.openDevice(SERIAL_PORT_THROTTLE, this->baud);
        }
        else {
            errorOpening = this->serial.openDevice(SERIAL_PORT_BRAKE, this->baud);
        }
        if (errorOpening != 1) return;
    }
    double read() {
        n = serial.readBytes(this->buf, sizeof(this->buf) - 1, 100); // timeout = 100ms
        this->buf[n] = '\0';
        if (n > 3) {
            try {
                curPos = std::stod(this->buf);
            }
            catch(std::invalid_argument& e) {
                curPos = 0;
            }
//            std::cout << curPos;
        }
        return curPos;
    }
};

int main() {

//    serialib serial;
//    serialib serial2;
//
//    char errorOpening = serial.openDevice(SERIAL_PORT, 9600);
//    char errorOpening

//    if (errorOpening != 1) return errorOpening;
//    printf("Successful connection to %s\n", SERIAL_PORT);

//    char buffer[256];

    serialDev wheel = serialDev(9600,false);
    serialDev wheel2 = serialDev(9600,true);
//    serialDev throttle = serialDev(11250);

    UINT DevID = DEV_ID; //literally fucking useless
    USHORT X = 30000;
    USHORT Y = 10000;
    USHORT Z = 10000;
    BYTE id = 1;
    BOOL ContinuousPOV=FALSE;

    if (!vJoyEnabled()) {
        std::cout << "VJoy Not Enabled";
        return -2;
    }
    if (!AcquireVJD(id)) {
        std::cout << "Failed to acquire vJoy device\n";
        return -2;
    }
    double xPos = 0;
    double xAdd = 0;
    double prevX;
    int cnt =0;
    double scale = 1;
    while (true) {
//        int n = serial.readBytes(buffer, sizeof(buffer) - 1, 100); // timeout = 100ms

//        if (n > 0) {
////            buffer[n] = '\0';
//            if (n > 3) {
//                xPos = std::fmod((std::stod(buffer) / 1200), 1); // one rev = 0->1
        double newX = wheel.read()/-150.0;
        if (newX<0.0) { newX = 0.0; }
        if (newX>1.0) { newX = 1.0; }
        X = (int) (newX * MAXRANGE);

        double newY = wheel2.read()/-190.0;
        if (newY<0.0) { newX = 0.0; }
        if (newY>1.0) { newX = 1.0; }
        Y = (int) (newY * MAXRANGE);

        if (cnt > 5) {
            std::cout << newX << std::endl;
            std::cout << newY << std::endl;
            cnt =0;
        }
        cnt++;

        id = (BYTE)DevID;
        iReport.bDevice = id;
        iReport.wAxisX = X;
        iReport.wAxisY = Y;
        iReport.wAxisZ = Z;

        if (!UpdateVJD(id,(PVOID)&iReport)) {
            std::cout << id;
            std::cout << " fialed \n";
            AcquireVJD(id);
            ContinuousPOV = (BOOL)GetVJDContPovNumber(id);

        }
//        else {
//            std::cout << "sending a pint \n";
//        }
    }

    wheel.serial.closeDevice();

}

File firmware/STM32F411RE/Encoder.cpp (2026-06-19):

#include <VescUart.h>
#include <HardwareTimer.h>
#include <Arduino.h>
#include "Encoder.h"

HardwareTimer *encoderTimer = new HardwareTimer(TIM2);

#define ENC_A PA0
#define ENC_B PA1

#define CPR 2400
#define MAXVAL 32767
#define MAXROT 1

int32_t Encoder::convertTicks(int32_t ticks) {
  float value = ((float)ticks / CPR / MAXROT) * MAXVAL;
  value = constrain(value, -32767.0f, 32767.0f);
  return (int32_t)value;
}

void Encoder::setup() {


  pinMode(ENC_A,INPUT);
  pinMode(ENC_B,INPUT);

  encoderTimer->setMode(1, TIMER_INPUT_CAPTURE_RISING, PA0);
  encoderTimer->setMode(2, TIMER_INPUT_CAPTURE_RISING, PA1);

  TIM2->SMCR &= ~TIM_SMCR_SMS;
  TIM2->SMCR |= TIM_SMCR_SMS_0 | TIM_SMCR_SMS_1;

  TIM2->CCMR1 &= ~(TIM_CCMR1_CC1S | TIM_CCMR1_CC2S);
  TIM2->CCMR1 |= TIM_CCMR1_CC1S_0 | TIM_CCMR1_CC2S_0;

  TIM2->CCER &= ~(TIM_CCER_CC1P | TIM_CCER_CC2P);

  TIM2->ARR = 0xFFFFFFFF; 
  TIM2->CNT = 0;

  lastSampleUs = micros();

  encoderTimer->resume();

}
void Encoder::loop() {
   uint32_t now = micros();
  uint32_t dtUs = now - lastSampleUs;

  if (dtUs < 1000) {
    return;
  }
  count = (int32_t)TIM2->CNT;
  currentPosition = convertTicks(count);


  positionChange = currentPosition - lastPosition;

  currentVelocity =
    (int32_t)(((int64_t)positionChange * 1000000LL) / dtUs);

  currentAcceleration =
    (int32_t)(((int64_t)(currentVelocity - lastVelocity) * 1000000LL) / dtUs);

  if (abs(currentVelocity) > maxVelocity) {
    maxVelocity = abs(currentVelocity);
  }
  if (maxVelocity < 1) {
    maxVelocity = 1;
  }
  if (abs(currentAcceleration) > currentAcceleration) {
    maxAcceleration = abs(currentAcceleration);
  }
  if (maxAcceleration < 1) {
    maxAcceleration = 1;
  }

  if (abs(positionChange) > maxPositionChange) {
    maxPositionChange = abs(positionChange);
  }
  if (maxPositionChange < 1) {
    maxPositionChange = 1;
  }



  lastPosition = currentPosition;
  lastVelocity = currentVelocity;
  lastSampleUs = now;
}

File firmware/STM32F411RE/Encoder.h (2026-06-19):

#pragma once
#include <Arduino.h>

class Encoder {
  private:
  int32_t convertTicks(int32_t ticks);
  int32_t lastPosition = 0;
  int32_t lastVelocity = 0;
  uint32_t lastSampleUs = 0;

  public:
  int32_t count;
  void setup();
  void loop();
  
  int32_t currentPosition = 0;
  int32_t maxValue = 32767;

  int32_t currentVelocity = 0;
  int32_t maxVelocity = 1;

  int32_t currentAcceleration = 0;
  int32_t maxAcceleration = 1;

  int32_t positionChange = 0;
  int32_t maxPositionChange = 1;
};

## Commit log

2026-06-14 Update CAD, Readme, BOM
    [5537T011_T-Slotted Framing (1).step, 5537T011_T-Slotted Framing.STEP.x_t, 6001ZZ Bearing.SLDPRT.step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]
2026-06-14 Readme updates, zine
    [BOM.csv]
2026-06-14 Small tweak (gearbox in future)
2026-06-16 Add labels for wiring
2026-06-19 Fixes for submission. Thanks for the feedback!
    [BOM.csv]
